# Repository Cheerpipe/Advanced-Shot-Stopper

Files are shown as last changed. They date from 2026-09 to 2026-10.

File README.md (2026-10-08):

<p align="center">
  Open Brew by Weight
</p>

# Open Brew by Weight

Open Brew by Weight adds brew-by-weight to an espresso machine: a Bluetooth
scale measures the drink, and an ESP32-S3 controller requests a stop near your
recipe's target weight. You keep using the machine's physical brew switch.

This repository provides firmware and hardware guidance for a DIY installation.
It is a work in progress, not a ready-to-install or certified kit. Development
started on the La Marzocco Linea Micra; other switch types have different wiring
and stop behavior.

> Before installation, read [Hardware](docs/HARDWARE.md) and complete the
> applicable [bench checks](docs/MANUAL_TEST_PLAN.md). The relay must remain open
> on startup, reset, power loss, and safety failure. Machine-specific wiring
> instructions are incomplete. See the [Disclaimer](#disclaimer).

## Start here

| I want to… | Read |
| --- | --- |
| Check whether my equipment fits | [Requirements](#requirements) and [machine types](#machine-types) |
| Prepare hardware and firmware | [Hardware](docs/HARDWARE.md) → [Build and USB installation](docs/BUILD.md) |
| Choose a controller and machine build | [Hardware and machine build profiles](docs/BUILD_PROFILES.md) |
| Connect and make the first shot | [First setup and daily use](docs/GETTING_STARTED.md) |
| Change how brewing works | [Features and settings](#main-features) |
| Integrate Open Brew by Weight with Home Assistant | [Home Assistant setup](docs/features/home-assistant.md) |
| Understand an unexpected result | [Troubleshooting](docs/FAQ.md) |
| Update or recover the controller | [OTA](docs/features/ota.md) / [Recovery](docs/EMERGENCY_RECOVERY.md) |
| Develop or contribute | [Contributing](CONTRIBUTING.md) |
| Understand the test gates | [Testing and validation](#testing-and-validation) |
| Look up a technical term | [Technical glossary](#technical-glossary) |
| Find a specific reference | [Documentation index](docs/README.md) |

## Requirements

- **Board:** the current built-in hardware profiles use an ESP32-S3 N16R8
  (16 MB flash / 8 MB PSRAM). The [development relay board](docs/HARDWARE.md#development-board)
  has a specific GPIO map; another board needs a complete reviewed profile.
- **Scale:** a supported Bluetooth model. Bookoo Themis Mini/Ultra were the
  primary development scales. Check the [model and capability table](libraries/EspressoScaleBLE/README.md#scale-compatibility);
  implemented protocols are not all equally tested.
- **Machine:** a compatible activation circuit connected only to isolated relay
  contacts, plus a physical switch input appropriate to the selected build.
- **Installation skills:** identify and verify your machine's electrical
  connections, build the firmware, and test the installation on a bench.

A [printable enclosure](docs/HARDWARE.md#3d-printable-enclosure) is included in
standard and thicker versions. PETG is recommended for the thick pair in
warmer installations.
Classic ESP32, boards without PSRAM, and Timemore scales are outside the current
support scope.

## How it works

The controller reads your brew switch separately from the machine's activation
circuit. It can therefore interpret your gesture and stop brewing according to
the scale, recipe guards, or time limits.

On paddle machines, the relay remains closed while brewing and opens to stop.
On momentary machines, it copies button presses and sends a pulse to request a
stop. **Opening that relay alone does not necessarily stop a momentary machine.**
See the distinctions below before choosing a build.

## Machine types

Prefer a named [hardware and machine build profile](docs/BUILD_PROFILES.md).
The selected machine profile resolves the corresponding compile-time type; it
is not a Web UI setting.

| Build | Value | How the controller knows the group is running |
| --- | ---: | --- |
| [Paddle / latch](docs/settings/paddle.md) | 0, default | Follows the maintained brew contact. Developed first for the Linea Micra. |
| [Momentary](docs/settings/momentary.md) | 1 | Infers flow from scale readings. Without confirmed flow, an automatic stop pulse may not be sent. |
| [Momentary + reed](docs/settings/momentary.md) | 2 | Uses an additional reed/hall input to observe the machine state. Preferred for momentary installations. |

Support for a switch model is not certification of a particular espresso
machine. The firmware's 60 s relay limit and the ability to stop water flow
are different on momentary machines; read the [stop limitations](docs/settings/momentary.md#stopping-and-time-limits).

This illustration shows the paddle-connector routing used during Micra
development. It is not a wiring schematic or pinout; verify the actual machine
circuit and follow the [hardware safety guidance](docs/HARDWARE.md) before installation.

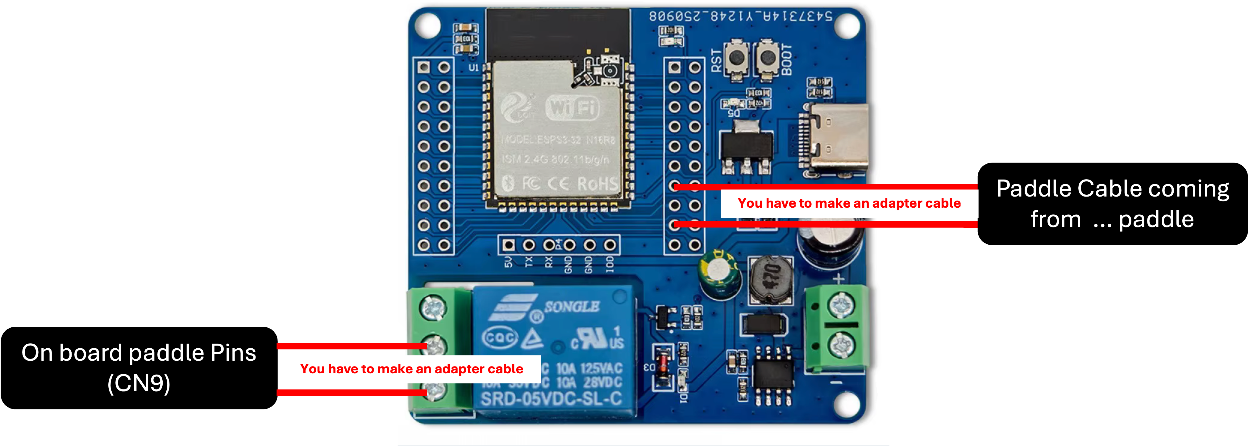
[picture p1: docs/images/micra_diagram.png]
Micra paddle connector and adapter-cable routing on the relay board


## Main features

| Need | Feature |
| --- | --- |
| Stop near a recipe weight | [Brew by weight](docs/features/brew-by-weight.md), with learned drip compensation |
| Use different recipes | [Presets](docs/features/presets.md), including factory Single and Double |
| Integrate with a Linea Micra | [La Marzocco Cloud](docs/settings/linea-micra.md) reads and sets preset brew-boiler temperatures and recognizes when the paddle is waking the machine instead of starting a brew |
| Place the cup after starting | [Tare and retare](docs/features/tare-retare.md) |
| Handle cup removal or bumps | [Cup protection](docs/features/cup-protection.md) |
| Handle unexpectedly fast or slow shots | [Fast](docs/features/fast-extraction-guard.md) and [Slow](docs/features/slow-extraction-guard.md) guards |
| Limit a shot after scale loss | [A→M time guard](docs/features/auto-to-manual.md) |
| Rinse with a switch gesture | [Quick rinse](docs/settings/quick-rinse.md), with a machine-profile default |
| Hear local feedback | [Alerts](docs/alerts.md), subject to scale/buzzer capabilities |
| Review results | [Shot history and statistics](docs/features/shot-history.md) |
| Integrate with Home Assistant | [Home Assistant](docs/features/home-assistant.md) |
| Update safely over Wi-Fi | [Dual-slot OTA](docs/features/ota.md), with automatic rollback |
| Send events to another local receiver | [Local HTTP webhooks](docs/features/webhooks.md) |

## Main settings

Recipe settings live in **Settings → Brew**. Machine and scale settings are
shared across recipes. [Presets](docs/features/presets.md) explains what is saved
and what a Home Quick Settings change affects.

The [documentation index](docs/README.md#settings) links each settings group.
Defaults are starting points; Fast and Slow guards can intentionally finish
above or below the target weight.

### Brew by weight: offset and learning factor

**Linear regression + offset correction** (`legacy` in API/CSV) applies the
full final-weight error to its learned stop offset. **Linear prediction +
adaptive EWMA** applies a fraction, α, of that error. Both stop toward
`target − learned offset`; **Baseline offset (g)** is the saved reset value
for either method, not an additional compensation.

For an eligible EWMA shot, `next offset = clamp(offset + α × (final − target), 0, 5)`.
For example, with target 36 g, final weight 36.20 g and offset 1.50 g:

| Current α | Next offset |
| --- | --- |
| 0.10 | 1.52 g |
| 0.30 | 1.56 g |
| 0.60 | 1.62 g |

A larger α responds faster to changes but also follows individual-shot noise
more strongly. A smaller α smooths that noise but adapts more slowly. An
underweight result reduces the offset so the next cutoff occurs later.
α learns between shots; it does not filter live scale readings or guarantee
better accuracy on a particular machine.

**Baseline learning factor (α)** is saved per preset, from 0.01 to 1.00 in
steps of 0.01, initially 0.30. Saving either base preserves current learning.
**Reset learned stop offset to baseline** resets only the selected offset;
EWMA keeps its current α. **Reset EWMA learning** restores both saved bases,
marks α initial and clears its evidence. Automatic learning may subsequently
choose 0.10, 0.30, 0.50 or 1.00; a custom α remains active until a candidate
earns a switch. See [BBW learning](docs/features/brew-by-weight.md#cutoff-behavior-and-learning)
for eligibility, comparison windows and persistence.

## First connection

After installation and bench verification, follow
[First setup and daily use](docs/GETTING_STARTED.md). It covers connecting to the
controller's access point, opening the Web UI, joining home Wi-Fi, selecting a
scale, and making the first shot. Once the controller has joined your home
Wi-Fi, reach the Web UI at `open-brew-by-weight.local`. Factory network details
are in [AP → First connection](docs/settings/ap.md#first-connection).

## Admin

Home and Settings use a browser claim; privileged actions also require Admin
unlock with the device password. These are separate controls:
[Web access](docs/GETTING_STARTED.md#web-access) explains both.

## Technical features

- [OTA updates](docs/features/ota.md) use an inactive firmware slot and boot
  verification. A bootable previous image is required for rollback.
- [Emergency recovery](docs/EMERGENCY_RECOVERY.md) restores access or resets
  settings using the physical switch.
- [Build and script reference](docs/SCRIPTS.md) covers supported ESP-IDF tooling.
- [Hardware and machine build profiles](docs/BUILD_PROFILES.md) defines the
  complete JSON profile, compatibility, override, and artifact contracts.

Remote start and rinse are **disabled by default**. A deliberate development
build can enable them; they are not part of the default operating workflow.
Remote Stop still requires Admin unlock. MQTT and persistent remote-control
integrations are outside the project goals. The Web UI provides status and
shot summaries, not a guaranteed real-time telemetry stream.

## Documentation

Use the [complete index](docs/README.md) for user guides, settings, architecture,
validation, and library integration. Read only the page needed for your task;
parameter tables and protocol contracts have one canonical home.

### Testing and validation

A **gate** is the set of checks that a change must pass before it can be accepted.
The project first classifies the changed files by risk, then runs the matching
gate. Higher levels include the lower-level checks, so a safety-critical change
receives much more scrutiny than a wording correction. The authoritative rules
and exact commands are in [Validation gates](VALIDATION.md).

| Level | What it is for | What it checks | When it runs |
| --- | --- | --- | --- |
| R0 | Non-critical documentation and repository metadata | Documentation contracts, local links, headings, images, and known paths | For documentation-only changes and as the base of every higher gate |
| R1 | Web UI, tests, developer tooling, and isolated logic | R0 plus the normal host tests and any focused checks or generated assets relevant to the change | While developing these areas and before submitting the finished change |
| R2 | BLE, networking, saved data, OTA, and build changes | Full host coverage, ASan/UBSan, TSAN, architecture rules, Web contracts, and every built-in compatible profile pair | When a change can affect integration, concurrency, memory safety, or a firmware image |
| R3 | Relay and machine control, ISR, watchdog, boot, GPIO, partitions, remote control, or an unknown path | R2 plus stricter compiler warnings, cppcheck, build variants, and the applicable HIL/manual evidence | Before accepting any safety-critical or not-yet-classified change |
| Release | A firmware image intended for distribution or installation | The complete automated analysis plus resource budgets, applicable soak tests, HIL, and the manual test plan | For a release candidate; a passing automated R3 run alone is not release approval |

**Host tests** run on the developer computer, without an ESP32 or
espresso machine. They are quick feedback for software behavior, but cannot prove
that real wiring, timing, radio conditions, or machine stopping are safe. The
focused profiles are:

| Profile | Purpose | When to use it |
| --- | --- | --- |
| `normal` | Runs the broad functional host suite without a sanitizer | During ordinary development and in every R1-or-higher gate |
| `asan` | Runs the host suite with ASan and UBSan to expose memory errors and undefined operations | For R2/R3 changes and when investigating crashes or suspicious memory behavior |
| `tsan` | Runs concurrent host scenarios with TSAN to find unsafe access to shared data | For R2/R3 changes and whenever task or thread ownership changes |
| `web` | Verifies generated Web UI assets and browser-facing contracts | After changing the Web UI, its source assets, or asset generation |
| `ble` | Focuses the normal host suite on scale protocols and BLE radio behavior | After changing scale communication or BLE protocols |
| `ota` | Exercises OTA host logic plus command-line and Web resilience cases | After changing firmware-update behavior or its interfaces |
| `tooling` | Checks the developer command facade, risk classification, and validation contracts | After changing scripts or repository workflow rules |

Run these profiles locally with `./scripts/dev test <profile>` and the risk
gates with `./scripts/dev validate --risk R0..R3`; `./scripts/dev classify`
determines the gate required for the changed paths. These commands do not
flash a board, operate the relay, or replace required HIL and manual evidence.

### Technical glossary

| Term | Meaning in this project |
| --- | --- |
| α (alpha) | The learning factor used by adaptive EWMA. It controls how much the latest eligible shot changes the learned stop offset. |
| A→M | **Automatic-to-manual** transition: brew-by-weight can no longer rely on the scale, so a time guard limits the remaining shot. |
| Admin unlock | A password-protected authorization required for privileged Web UI actions; it is separate from claiming the browser session. |
| AGPL-3.0 | GNU Affero General Public License version 3, the repository's current copyleft license. Network use of a modified version can require offering its corresponding source code. |
| AI | Artificial intelligence. The README notes its use during project development. |
| API | Application Programming Interface: a defined way for software components or external integrations to exchange commands and data. |
| ASan | **AddressSanitizer**, a host-test instrument that detects invalid memory access, such as reading past a buffer or using freed memory. |
| BLE | Bluetooth Low Energy, the wireless link used to communicate with supported scales. |
| BBW | **Brew by weight**, the feature that uses live scale measurements to request a stop near the recipe target. |
| Baseline | A saved starting value to which learned settings can be reset. It is not an extra correction added to the current value. |
| Boot / boot verification | Boot is the controller's startup process. After OTA, verification confirms that the new image started safely before it is kept. |
| Browser claim | The controller's way of assigning ordinary Home and Settings access to a browser session; it does not grant Admin privileges. |
| CI | Continuous Integration, the practice of running automated checks on every change. This repository runs its checks locally through `./scripts/dev` instead of a hosted pipeline. |
| Clamp | To restrict a calculated value to a minimum and maximum; the README's formula keeps the learned offset between 0 g and 5 g. |
| Compile-time setting | A choice fixed while firmware is built. Changing it requires a new build; it cannot be changed later in the Web UI. |
| CSV | Comma-Separated Values, a plain-text tabular format used when exporting or exchanging shot data. |
| Cutoff / stop offset | The point at which the controller requests a stop before the target weight, allowing for coffee that continues to drip. The learned offset is adjusted from previous eligible shots. |
| DIY | Do it yourself: the user assembles, installs, and validates the hardware rather than receiving a certified finished product. |
| Drip compensation | Stopping early enough to account for liquid that continues reaching the cup after the machine receives the stop request. |
| ESP32-S3 | The Espressif microcontroller family on which the controller firmware runs. |
| ESP-IDF | Espressif IoT Development Framework, the supported toolchain and software framework used to build the firmware. |
| EWMA | Exponentially Weighted Moving Average, the adaptive learning method that applies a chosen fraction of the latest final-weight error instead of the entire error. |
| Firmware | Software built to run on the ESP32-S3 controller rather than on the user's computer or browser. |
| Firmware slot | One of the flash-memory regions that can hold a bootable firmware image. OTA writes the inactive slot so the previous image remains available for rollback. |
| Flash memory | Non-volatile storage that keeps firmware when power is removed; it is distinct from working memory such as PSRAM. |
| Gate | The complete set of automated checks and, where required, physical evidence demanded for a change's risk level. |
| GPIO | General-Purpose Input/Output, a configurable electrical pin used to sense a switch or control a signal. Its assignment and polarity are safety-critical here. |
| Guard | A protective rule that stops or limits a shot when measured behavior is outside the recipe's expected conditions. |
| HIL | Hardware in the loop: testing with the real controller or representative electrical hardware so physical timing and I/O behavior can be observed. |
| Host test | A test compiled and run on a computer, without operating the ESP32, relay, or espresso machine. |
| HTTP | Hypertext Transfer Protocol, used by the local Web UI, webhooks, and update-related interfaces. |
| ISR | Interrupt Service Routine, code that responds immediately to a hardware event and must obey stricter timing and concurrency rules. |
| K2 | The README's example name for an optional external safety relay or barrier; its actual design depends on the machine and jurisdiction. |
| MB | Megabyte, used here to describe flash and PSRAM capacity. |
| MIT License | The permissive license that applies to identified upstream portions and historical snapshots, not to the repository's current work as a whole. |
| Momentary machine / pulse | A momentary machine changes state after a brief button-like electrical signal, called a pulse, rather than following a maintained switch position. |
| MQTT | Message Queuing Telemetry Transport, a publish/subscribe messaging protocol; persistent MQTT remote control is outside this project's goals. |
| n8r4 / n16r8 | Supported memory variants: the number after `n` is flash capacity in MB and the number after `r` is PSRAM capacity in MB. |
| OTA | Over-the-air update: installing firmware over Wi-Fi into an inactive firmware slot, followed by boot verification and possible rollback. |
| Paddle / latch | A maintained physical switch: its state directly represents the requested brew state. |
| PETG | Polyethylene terephthalate glycol, a 3D-printing material recommended for the thicker enclosure parts in warmer installations. |
| Pinout / GPIO map | The documented assignment between board pins and electrical functions. A different board requires a reviewed assignment. |
| Preset | A saved recipe and its related brew settings, such as target weight and learned values. |
| PSRAM | Pseudostatic RAM, external working memory fitted to the supported ESP32-S3 boards. |
| Reed / Hall input | A magnetic sensor input used by the preferred momentary-machine configuration to observe whether the machine is running. |
| Regression | Here, a mathematical method that estimates drip behavior from previous eligible shots to improve the stop point. |
| Relay / isolated contacts | An electrically controlled switch whose contact side is kept separate from the controller side. The project uses it to request machine activation or stopping. |
| Rollback | Returning to the previous bootable firmware image when a new OTA image fails verification. |
| Sanitizer | A test-build instrument that watches a running program for classes of bugs that ordinary functional assertions may miss. |
| Soak test | A long or repeated run used to reveal resource leaks, timing drift, or failures that short tests may not expose. |
| Static analysis / cppcheck | Inspection of source code without executing it, used to detect suspicious constructs and rule violations. `cppcheck` is one analyzer used by the R3 gate. |
| Tare / retare | Setting the scale's current load to zero; retare repeats that action when the workflow needs a new zero reference. |
| Telemetry | Status or measurement data reported while a system runs. The Web UI is not promised as a guaranteed real-time telemetry channel. |
| TSAN | **ThreadSanitizer**, a host-test instrument that detects data races: unsafely coordinated simultaneous access to shared data by multiple threads. |
| UBSan | **UndefinedBehaviorSanitizer**, a host-test instrument that detects invalid C/C++ operations whose result the language does not define. |
| USB | Universal Serial Bus, used to install firmware, monitor serial output, and issue supported maintenance commands. |
| Watchdog | A timer that detects software that has stopped making required progress and triggers a controlled recovery. |
| Web UI | The browser-based user interface served by the controller. |
| Webhook | An HTTP request sent to another local service when a configured event occurs. |
| Wi-Fi / access point (AP) | Wi-Fi is the local wireless network technology; in access-point mode the controller creates its own temporary network for first setup or recovery. |

## Disclaimer

**Use at your own risk.** Anyone who builds, installs, configures, or operates
firmware from this repository does so **under their sole responsibility**. The
authors and contributors **accept no liability** for any harm, loss, or damage
whatsoever — including but not limited to **personal injury, death, property
damage, equipment damage, business interruption, or psychological distress** —
arising from the use or misuse of this software, documentation, or any
derivative work.

You are solely responsible for:

- **Designing and building a correct, safe circuit** — suitable relay or contact,
  electrical isolation, ratings, polarity, feedback, and any external safety
  barrier (e.g. K2) appropriate for your machine and jurisdiction.
- **Installing and verifying that circuit** on your equipment, including bench
  tests and the full [manual test plan](docs/MANUAL_TEST_PLAN.md) before
  connecting to a live espresso machine.
- **Configuring the firmware correctly and safely** — including GPIO assignment,
  compile-time pin maps, polarity, machine circuit limits, and workflow parameters — so
  that paddle readback, machine control, and automatic stop behavior match your
  hardware. GPIO and other safety-critical pin assignments are **not**
  configurable from the Web UI; they must be set in source and verified at
  build time (see [Hardware](docs/HARDWARE.md) and the [FAQ](docs/FAQ.md)).

**Espresso machines are inherently hazardous.** A machine such as the La
Marzocco Linea Micra contains **pressurized boilers, hot water, and steam at high
temperature**. Adding automatic or remote control — including brew-by-weight
stop, relay actuation, Wi-Fi commands, and timer-based limits — can increase
risk if wiring, isolation, configuration, or software behavior is wrong.
Malfunction or misconfiguration could leave the brew circuit energized too long,
defeat intended safety interlocks, or cause scalding, flooding, electrical
hazard, or fire. **Do not connect this firmware to mains-powered espresso
equipment unless you understand these risks and have validated your entire
system on the bench first.**

This project provides software and documentation only. It **does not**
certify, warrant, or guarantee safe operation on any machine. No statement in
this repository should be interpreted as professional electrical, plumbing, or
machinery safety advice.

This project was developed with substantial assistance from artificial
intelligence tools. AI helped with design, implementation, documentation, and
testing workflows; human review, hardware validation, and safety judgment remain
the author’s responsibility. Use on real espresso equipment only after you have
verified wiring, isolation, and behavior on your own setup.

## License

Open Brew by Weight is licensed under the
[GNU Affero General Public License v3.0](LICENSE) (AGPL-3.0).

You may use, modify, and distribute it freely, including for commercial
purposes. If you distribute a modified version, or offer one to users over a
network, you must provide the complete corresponding source code under the
AGPL. Closed proprietary forks are not allowed.

Earlier snapshots of this repository were published under the MIT License.
Those historical releases remain available to their recipients under MIT.
Portions derive from [tatemazer/AcaiaArduinoBLE](https://github.com/tatemazer/AcaiaArduinoBLE)
(MIT); see [LICENSE](LICENSE) for the full terms and upstream notice.

## Credits

Open Brew by Weight is maintained by **Felipe Urzúa**
(`cheerpipe@gmail.com`) —
[Cheerpipe/AcaiaArduinoBLE](https://github.com/Cheerpipe/AcaiaArduinoBLE).

It would not exist without
**[tatemazer](https://github.com/tatemazer)** and
[tatemazer/AcaiaArduinoBLE](https://github.com/tatemazer/AcaiaArduinoBLE).
That project proved BLE brew-by-weight stop, shared the core scale protocol
work, and shipped the original Shot Stopper as a plug-and-play kit. This
application firmware, Web UI, paddle and momentary machine models, and safety
workflow are new work on top of that foundation.

Thanks to **[AtomHeart-Lang](https://github.com/AtomHeart-Lang)** for AtomHeart
Eclair scale support, contributed upstream in
[tatemazer/AcaiaArduinoBLE#41](https://github.com/tatemazer/AcaiaArduinoBLE/pull/41).
That work is vendored here and keeps Eclair in the supported scale set.

The vendored library also credits:

- [LunarGateway](https://github.com/frowin/LunarGateway/) (frowin)
- [pyacaia](https://github.com/lucapinello/pyacaia) (lucapinello)
- Felicita Arc: baettigp, A-TWJ
- Bookoo: philgood, same31
- AtomHeart Eclair: [AtomHeart-Lang](https://github.com/AtomHeart-Lang)
- Decent, DiFluid, MyScale, Varia, Eureka, WeighMyBru: protocol knowledge from
  [gaggimate/esp-arduino-ble-scales](https://github.com/gaggimate/esp-arduino-ble-scales)
  ([jniebuhr](https://github.com/jniebuhr) et al.), reimplemented here without
  copying source
- Lunar 2019: jniebuhr

See the [library acknowledgement](libraries/EspressoScaleBLE/README.md#acknowledgement).

Runtime and tooling:

- [Espressif ESP-IDF](https://github.com/espressif/esp-idf)
- [Arduino-ESP32](https://github.com/espressif/arduino-esp32)

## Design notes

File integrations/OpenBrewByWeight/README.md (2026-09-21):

# Open Brew by Weight for Home Assistant

This HACS custom integration connects Home Assistant 2026.9 or newer to one
Open Brew by Weight controller over the local network. It provides live shot
state, controller-restored shot measurements, durable preset selection, seven
Home Quick Settings switches, and a safe restart button. It never starts or
stops the espresso machine.

## Install

After the dedicated integration repository publishes a release, add that
repository to HACS as an **Integration**, install **Open Brew by Weight**, and
restart Home Assistant. During development, copy
`custom_components/open_brew_by_weight` into Home Assistant's
`custom_components` directory.

The controller must run firmware with integration API version 1. Set Home
Assistant's Internal URL to a LAN-reachable `http://` address. Both devices must
be on the same trusted network.

## Configure

If the controller is on a network that passes multicast, it appears
automatically under **Discovered** in **Settings → Devices & services**;
confirming it is the only step needed. Otherwise add **Open Brew by Weight**
manually and enter the controller IP address or local host name. Confirm
webhook takeover only if Home Assistant should replace the existing receiver.

Setup registers and tests the local callback before entities appear. The
controller API is intentionally open on the trusted LAN, like its Web UI. The
webhook ID is not included in entities or diagnostics.

## What it provides

- One controller device and 17 translated sensors.
- Last completed and last qualifying-good shot values: duration, final and
  target weight, average flow, first drop, type, stop detail, and preset name.
- A non-optimistic **Active preset** select backed by stable preset IDs.
- Seven non-optimistic Quick Settings switches and a shot-safe **Restart Open
  Brew by Weight** button.
- Immediate webhook updates with bounded reconciliation after commands,
  revision gaps, controller startup, or runtime failure; no periodic polling.
- Transactional address/webhook reconfiguration, redacted diagnostics, clean
  unload, and conditional removal cleanup.

A “good” shot retains the former YAML example's continuity rule: over 12
seconds and over 2 grams. It is not a quality rating.

## Limitations and common errors

- The controller supports one HTTP callback and no HTTPS callback.
- The controller API has no authentication and relies on the trusted LAN.
- Webhook delivery is best effort; a missed final event may remain stale until
  the next command, revision gap, controller-start hint, or reload.
- Preset and Quick Settings changes are rejected while the controller's
  existing safe-state gate is closed. Restart may be requested during a shot
  but waits until the controller is idle.
- A silent power loss cannot be detected before a REST operation fails because
  the integration deliberately has no polling heartbeat.
- Automatic discovery needs multicast on the network; guest and hotel Wi-Fi
  that blocks it falls back to manual IP/host setup.

Use **Reconfigure** to view or rotate the administrator-only webhook ID, change
the address, or resend/test the current callback. Deleting the entry clears
only a callback it still owns.

Full setup, migration, entity, update, and troubleshooting details are in the
[Home Assistant guide](../../docs/features/home-assistant.md). The wire contract
is in the [Integration API](../../docs/INTEGRATION_API.md).

## License

Copyright 2024–2026 Felipe Urzúa and contributors. This integration is licensed
under AGPL-3.0-or-later with the rest of Open Brew by Weight.

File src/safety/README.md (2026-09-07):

# Safety service boundary

Safety remains behind the stable root headers while R3 extractions require HIL.
Do not move relay, timer, watchdog, boot, or GPIO behavior together with a
functional change. The root `AGENTS.md` invariants and `VALIDATION.md` R3 gate
apply to every file in this directory.

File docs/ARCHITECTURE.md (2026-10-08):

# Firmware architecture and ownership

Use this reference when changing module boundaries. For the runtime sequence,
read [State machines](STATE_MACHINES.md); for a first code change, start with
[Contributing](../CONTRIBUTING.md).

The integration roots `src/openBrewByWeight.cpp` and `src/OpenBrewByWeightNetwork.cpp`
assemble implementation fragments in `src/control/`, `scale/`, `network/`,
`persistence/`, `diagnostics/`, and `platform/`. Fragments compile in their
owning translation unit. Shared headers carry fixed-size values, pure policy,
or explicit callback tables; each service owns its mutable state.

| Service | Owns mutable state | Accepts | Publishes |
|---|---|---|---|
| SafetyKernel | relay, safety timers, watchdog and reset history | bounded control intention | `RelaySafetySnapshot`, safety events |
| ControlOrchestrator | active session, cup/recipe policy and command arbitration | scale/machine/network messages | fixed-size control snapshots and commands |
| ScaleService | BLE central link, scale queues and radio policy | `ScaleCommand`, immutable worker policy | `ScaleEvent`, `ScaleLinkSnapshot`, RF state callback |
| SelectedMachineIntegration | concrete machine integration state; absent integrations use a no-op adapter | common lifecycle/config, physical-start disposition and optional backflush contract | normalized bounded backflush observations plus private feature status; no universal feature model |
| NetworkService | Wi-Fi/httpd/mDNS, request parsing and webhook transport | `NetworkBridgeCallbacks`, control snapshots | `WebCommand`, transport diagnostics |
| PersistenceService | NVS/EEPROM/partition serialization and write schedule | fixed-size records | success/failure result messages |
| DiagnosticsService | logs, counters, task/heap snapshots and exports | observational snapshots | JSON/serial evidence only |

## Dependency rules

1. SafetyKernel never includes or calls Wi-Fi, HTTP, JSON, webhook or network
   code. Its ISR path remains fixed-size, internal-memory-only and nonblocking.
2. ScaleService never references the `networkManager` singleton. Radio state
   crosses `ScaleWorkerBridgeCallbacks`, configured once before its task starts.
3. NetworkService requests control effects only through
   `NetworkBridgeCallbacks`; it cannot call machine/relay implementation APIs.
4. Persistence owns durable writes. Other services publish fixed-size requests
   and do not hold task/spin locks across flash I/O.
5. Diagnostics are observational. No diagnostic result authorizes the relay or
   mutates session state.
6. C task handles are borrowed lifecycle tokens: their owner must execute
   stop/ack/join. Other ESP/FreeRTOS handles use a unique non-allocating owner
   or an explicitly documented static lifetime.
7. Common machine-integration code exposes lifecycle hooks, physical-start
   disposition and an optional normalized backflush observation contract.
   Native protocol, authentication and provider policy remain in the selected
   module. Unsupported integrations return no permission. CMake compiles exactly
   one concrete adapter and only its private component dependencies.

`scripts/check_architecture.py` gates these rules and caps growth of the three
legacy concentration points. The caps are not quality targets: when a feature
would exceed one, extract it into its owning service rather than raising the
limit. Current independent host harnesses exercise SafetyKernel, OTA,
persistence, webhook policy, BLE protocol/runtime and shared resource owners
without including either monolithic integration root.

## Machine integration modules

The machine profile declares an allow-listed `integration` value explicitly;
brand, model, ID and display text never select executable code. Profiles with
`integration: none` compile the no-op adapter and do not link a concrete machine
protocol component. Linea Micra builds compile its adapter, service, bounded
feature types, HTTPS cloud client and the pinned WSS/STOMP observer. Future machines may expose entirely
different feature APIs while retaining only the small lifecycle boundary needed
by boot, network-state publication, and generic physical-start disposition.

The Micra adapter owns a dedicated low-priority worker, bounded PSRAM response
workspace, and a PSRAM-only mbedTLS allocation profile so transient handshakes
do not fragment internal DRAM. It registers an installation key, signs La
Marzocco cloud requests, keeps short-lived access and refresh tokens in RAM,
lists account machines, and reads only the selected serial's dashboard. The
network service publishes STA, AP, and shot state through the common lifecycle
boundary. The worker never starts cloud work without STA, cancels it when AP
starts or STA is lost, and pauses state observations during shots. It has no
NimBLE dependency and cannot delay scale discovery, scale commands, or weight
delivery.

The Micra service also owns power-state freshness and the optimistic ON/OFF
overlay lifetime.
Its adapter returns normal, wake, backflush-candidate or cleaning-blocked
physical-start dispositions. Control consumes them before brew, rinse, guards
and scale effects; those subsystems never depend on Micra types.

Backflush uses an optional common bounded handoff of eight ordered transitions,
copied under the integration mutex and drained only by control. Opaque
continuity, episode and first-ingress attempt tokens fence discontinuities and
pre-edge frames. Micra owns native state, transport liveness and qualification;
control owns candidate/running activity without a brew session. The existing
relay driver alone promotes a live 60-second candidate to the original close
time plus 180 seconds, transactionally replacing its independent and task
deadlines. Every non-active state after confirmation, observation loss, physical
release or safety failure opens the relay. The end path appends one electrical
duration record without scale commands, shot statistics or brew events.

The schema-3 settings blob retains the 312-byte
`LineaMicraPersistedSettings` record in every profile. The connection byte at
record offset 311 occupies prior enclosing-blob padding: Micra offset 2991,
checksum offset 3304 and total size 3312 remain unchanged. Values are explicitly
WebSocket=0 and API=1. Schema 1/2 blobs are authenticated against their original
CRC before an in-memory migration defaults the new byte; v1 also enables the
existing touch-stop fallback. Load never writes back. Settings saves and resets
wait for successful OTA trial confirmation, preserving the old durable records
for rollback. This admission does not gate boot readiness or other stores.

One facade reduces HTTP and WebSocket field updates. Each admitted subscription
queues one initial dashboard cycle in the existing HTTP worker, concurrent with
push reception. Its identity, epoch, connection revision and independent field
revisions are captured at subscription; ordinary reads capture them at request
start. Both capture intent at request start; callbacks capture intent when a
fragmented message starts. Old results cannot overwrite newer push evidence or
offline/reconnect transitions. Compatible queued reads coalesce; post-command
reconciliation retains its request-time field baseline. Accepted power alone
changes its source (`api_initial`, `api`, `websocket`) and synchronization.
WebSocket power stays current during healthy silence; API mode retains its
30-second age limit. Accepted commands do not fabricate power/temperature samples.
A 60-second optimistic overlay and a separate stale suspension hold preserve
the effective power without changing the last cloud evidence timestamp.
The SDK callback publishes decoded updates under the facade mutex, independently
of the HTTP worker. Only the worker stops/destroys the WebSocket.
Observation pauses require both an admitted shot and a currently connected
scale. Scale loss or rinse classification releases the pause. Unscaled shots,
wake, backflush and rejected starts keep observation available. Actual-shot
command safety and relay-critical webhook/NTP admission remain independent
of the scale-qualified transport pause.

Scale discovery publishes a generic atomic inhibit before exposing an eligible
Candidate mailbox. Micra HTTP, webhooks and NTP consume it, regardless of
machine profile. Discovery releases acquisition at Ready, or after five seconds
of actual scan opportunity without a candidate. Setup, shot and the library's
three-second quiet interval remain separate gates. Local access remains active;
this is transport quiescence, not a physical RF-silence guarantee. Micra WSS is
excluded from the scale inhibit so backflush supervision survives BLE acquisition.

## BBW policy and storage

Brew-by-weight uses a single cutoff policy: linear prediction with adaptive
EWMA learning (the regression mode was removed; persisted `algorithm=0`
blobs are aliased to EWMA at settings load). Shared scale qualification,
direct confirmation, guards, control arbitration and machine/safety authority
remain outside the policy. The original trend fit remains shared with accidental
touch sensing; only EWMA cutoff uses centered OLS. Strategies neither actuate
hardware nor write flash.

Control owns `BbwLearningBank`: up to eight identity-keyed states, under 3,000
bytes total, with 20 observations and five trajectory anchors per preset.
Four fixed gains compete against the current gain, including a custom incumbent.
Scoring replays the retained window from its anchors and is bounded
post-finalization work, with no allocation or per-sample persistence. The cycle
and pending finalizer capture preset, algorithm/profile, full-precision offset,
actual alpha and a per-learner generation. Learning checks the originating state;
reset/delete/recreation or a conflicting update invalidates it. Recipe changes
clear evidence; algorithm-only selection freezes/resumes retained EWMA state.
Editing reset bases alone preserves current learning and evidence.
Settings status publishes active-preset identity, both offsets, alpha baseline, gain/provenance
and evidence count together in the existing coherent control snapshot.

Settings schema 3 uses the current 344-byte `RuntimeConfig`, 104-byte
`ShotPreset`, and 3,312-byte settings blob. Candidate
anchors/observations/generations are RAM only; deferred persistence retains
offsets, gain/provenance, and profile through the existing dual-slot owner.
`powerManagementEnabled`, webhook preset delivery, and Allow rinse while Armed
are current explicit fields. Presets never copy the global power setting.
The schema-1 upgrade names former padding at runtime byte 17 and preset byte 46
for `touchStopFallbackEnabled`; it initializes both to true before semantic
validation. Schema-2/3 records preserve explicit false. Blob sizes, revisions and
dual-slot ownership remain unchanged. Other lengths and schemas are rejected.
The shot log is the authority for a completed shot: confirmed, non-rinse,
strictly more than 12,000 ms of brewing and a finite settled yield strictly
above 2 g. The fixed recording threshold does not alter the configurable BBW
protection window or actuation. Home and the integration snapshot resolve the
newest eligible log record by ID under `shotStoreMutex`; the curve sidecar and
rating use that same ID. Deleting the newest record advances Home to the next
eligible row, and clearing the log empties the idle card. The in-progress card
continues to use the live control snapshot. The legacy `LastShotStore` blob
remains in the binary layout for internal completed-cycle diagnostics, but its
separate good-shot field is not a public shot authority. An erase-all install
starts both histories empty; no upgrade migration is required.

History schema 1 keeps the current fixed records and entries. Guard byte bits 5–7 encode
profile (0 unknown, 1 pre-selector regression with unknown version, 2 regression v1,
3 adaptive EWMA v1, 4 EWMA v2). Alpha is 0 unknown or 1–100 hundredths;
extension bits 2–4 hold its low three bits, cut-type bits 4–7 its high four.
Extension bits 5–6 encode learning application (0 unknown,
1 skipped, 2 applied). Guard, rating, extension and weight-source meanings are
preserved in the current layout. Shot-type bits 2–7 and cut-type
bits 2–3 hold the captured preset ID (low six/high two bits); type/cut readers
mask the low two bits. Preset/BBW writers preserve each other's bit fields.
Any non-v1 history store is discarded instead of decoded. The ID follows
existing preset allocation, while the stored name is historical data rather
than a lookup through the current preset bank.
Stats values are derived under the store mutex from shot records in RAM;
no aggregate is persisted. The read visits at most 100 ring entries and copies
at most ten records for general metrics. BBW error has its own ten-cut window
across the same ring, counting normal target or legacy prediction cuts only.
Available flow is counted separately within the general window.

The stats shot log, its curve sidecar, and the independent activation history
are owned by one RAM data layer (`ActivationStores`) whose every access runs
under the single `shotStoreMutex`. Control and HTTP mutate only RAM and advance
a generation. Control housekeeping captures an immutable image under that
mutex: clean shot/activation stores skip their record payloads, and the curve
image carries only the uncommitted suffix plus block, deletion and epoch metadata.
Oldest-first curve commits preserve this suffix across retries and ring eviction.
The image is dispatched to the core-0 persistence worker. The worker performs
flash I/O without the store mutex. Control acknowledges completion and clears
live dirtiness only when the completion generation still matches.
Acknowledgement carries the image's
flash progress back to each live store even when newer RAM edits remain dirty,
so the next snapshot advances from the committed physical state. ShotLog and
History keep their two-slot generations; curves use block sequences, retention
floors and clear epochs. The manual scale
profiler follows the same deferred pattern: the health worker owns one
bounded PSRAM capture of raw decoded weights plus correlated firmware
decisions, and the persistence worker commits the completed trace to a
dedicated flash partition with the validity-bearing header written last.
Capture ends at record capacity or on request, with a reserved terminal slot;
there is no elapsed-time cutoff. Its 256 KiB PSRAM payload and 256 KiB flash
payload hold the same trace, so they are not additive capacity. The health
worker maintains a constant-memory, time-based EWMA of record growth for the
advisory remaining-time estimate. Persistence state remains separate from
capture occupancy. Existing record/header fields extend timestamps without
changing the 32-byte record size or partition layout; see the
[diagnostic API](INTEGRATION_API.md#post-apiv1diagnosticscale-profile).
Each inactive slot or used curve sector is
erased one 4 KiB sector at a time, programmed one 1 KiB staged chunk at a time,
and receives its validity-bearing header last; the worker rechecks the current
machine and scale gates between steps. The shot log's whole 10,828-byte store and the
16,024-byte activation-history store live in PSRAM and move to and from their
slots in 1 KiB chunks staged through the small internal flash-I/O scratch only
while that owner holds the flash lock. Each keeps two slots in its own data
partition — 2×12 KiB for `shotlog`, 2×16 KiB for `history` — with generation
and checksum selection preserving the atomic whole-store update; a failed
write never erases the last-good slot. Writes remain deferred until the shot
has ended. The shot log uses schema 2 in its dedicated partition; any other
schema is discarded and the shot history starts empty.

On n16r8, ESP-IDF writes one ELF core dump to a 640 KiB capture partition
after a panic. Once the relay is open and the durable boot ID has been saved,
boot code validates that image and promotes it into one of two 704 KiB slots
in the crash-history partition. Each slot commits a checksum-protected metadata
sector last, after the dump copy and SHA-256 verification. The copy replaces
the oldest valid slot only when both slots are occupied; interruption before
commit leaves the capture available for retry. The capture's first sector is
erased only after commit, so a reboot between those operations is recognized
by the boot ID and dump digest. HTTP download reads bounded chunks under the
shared flash lock and releases the lock before sending each chunk. The raw
archive requires Admin unlock because task stacks may contain secrets.

The shot-curve sidecar uses schema 3. Each accepted extraction or drip weight is paired
with its relative reception time in milliseconds; repeated weights and equal
timestamps remain observations. The 1201-observation capacity covers a 60 s
shot with observations at least 50 ms apart. That spacing is a capacity
assumption, not a grid or rate limiter. Known rejected observations, reference
changes and link discontinuities mark the next accepted observation as a new
segment. Overflow preserves the prefix, marks it incomplete and leaves control
and scalar history running.

The 4984-byte RAM record and 498420-byte 100-record cache live in PSRAM.
Curve events also preserve elapsed milliseconds in 16-bit fields, with
`UINT16_MAX` reserved for unavailable values. Sidecar schema 3 distinguishes
these fields from previous decisecond events; older curve records are discarded
without changing scalar history, settings, partition addresses or OTA slots.
Curve JSON keeps the seconds-based `dropS`, `extendedS`, `atmS`, `atmClearedS`
and `endS` fields with three decimal places; scalar shot metrics retain their
existing precision and meaning.
An 816 KiB dedicated partition holds 101 reserved 8 KiB data blocks and two
4 KiB clear-epoch sectors. A maximum-size record occupies 5012 bytes. Writes
erase only its one or two used physical sectors, transfer only the used record
through the existing internal 1 KiB scratch, and commit the checksum-bearing
header last. A replacement uses the spare block, retaining the previous 100
records until commit. Startup scans only block starts, checks schema, lengths,
counts, times and checksums, and reconstructs the newest retained records.
Deletion clears a validity bit; the committed retention floor prevents old
evicted curves from returning after deletion. Alternating clear epochs prevent
curves from returning when shot IDs are reused. Immutable worker acknowledgement
carries physical progress forward while newer RAM mutations stay dirty.

Capture performs no flash I/O. After cutoff, control appends valid same-connection
drip observations to the pending curve until finalization or cup discontinuity.
The existing 1201-reading/60-second bounds include this tail; overflow retains
the captured prefix and sets `wTruncated`. Rejected readings, reference changes
and link discontinuities retain segment breaks. The cutoff event keeps its
original time; accepted post-drip yield updates its separate weight annotation.
No schema, record-size or partition change is required, and existing schema-3
records remain readable after OTA. Curve
JSON exposes aligned `wCg`/`wAtMs`, segment-start indices in
`wBreakBefore`, and `wTruncated`. Weight and flow consumers use actual
times; event annotations never become observed samples. The Web weight chart
draws post-cutoff observations dashed without fill and uses a fixed-size hollow
marker only when the complete tail's last observation matches settled yield.
Flow applies the same supported-window estimator to extraction and drip readings;
CSV includes both. Its faint, unfilled dashed continuation starts at cutoff,
with a visual-only interpolated boundary when continuous support exists.
Post-cutoff endpoint estimates with midpoints before cutoff do not alter the
earlier solid trace. Extraction Max flow excludes post-cutoff endpoints, while
the plot range includes drip rates. Scalar shot metrics,
independent Stats eligibility windows, sorting and exact-ID joins remain owned
by ShotLog. Other curve schemas start empty. OTA remains supported after the
one-time preserving USB layout transition.

Decoding checks the supplied length before reading record CRCs and copies only
that validated length; compact inputs do not require a full-store allocation.
Profile rules are immutable: changing prediction, gain candidates or eligibility
requires versioned compatibility, not relabeling historical data. Numeric and
user contracts are in [BBW](features/brew-by-weight.md#cutoff-behavior-and-learning)
and [shot history](features/shot-history.md).

## Live settings notifications

The global `timezoneId` is an IANA region/city string in the schema-3 settings
blob. Network validates it against the firmware's generated tzdata2026d
catalog; control owns the effective setting and first-auto provenance; the
existing persistence worker saves both in the same settings generation.
The `timezoneAutomatic` preference occupies former runtime padding at byte 6,
preserving the remaining layout. Saved zones and their provenance survive both
same-schema OTA updates and the supported schema-1/2 to schema-3 conversions.
Automatic time zone defaults to on for new records.
Flash persistence publishes `timezoneInitialized` only after loading a valid
saved zone or verifying a settings write containing one; factory reset clears
it. Until then, a zone-only browser initialization is permitted without Admin.
Once initialized, zone-only browser updates require saved automatic mode.
Other date/time patches, including mode changes, still require Admin. Control
rechecks the revision and automatic-update eligibility before applying commands;
the existing worker retries persistence failures without repeated UI writes.
`src/ShotStopperTimeZoneData.h` is an immutable flash table of 597 supported
IDs and 4,341 transitions, deduplicated into 67 schedules for UTC instants in
2025–2099. `scripts/generate_timezones.py` regenerates it from the pinned
upstream archive without runtime allocation or a global C library `TZ` state.
There is no mutable catalog copy or per-request allocation. On n16r8, the
existing PSRAM XIP profile places this read-only data in PSRAM at startup;
other profiles keep their configured read-only mapping. The API exposes the current
zone and the offset resolved at the current UTC instant separately. Without a
configured/resolvable zone, UTC offset zero is the explicit fallback.

The control task captures UTC and its resolved offset when a cycle ends.
Pending shot finalization keeps that pair in RAM through drip delay; the shot
and activation stores retain their existing UTC/local/offset representation
without a storage migration. NTP continues to own UTC synchronization and
does not change the monotonic control timers. The Web preview resolves a draft
zone without saving it; a browser UTC estimate is used only for preview when
the controller clock is unavailable.

First-auto provenance reads UTC once under the wall-clock owner's lock so
its timestamp and quality cannot disagree during an NTP state transition.
Configuration and preset saves are acknowledged by their request ID and
result, together with the resulting revision; unrelated revision changes do
not acknowledge a pending command. Applied settings may still await the
existing asynchronous persistence worker.

Live settings commit publishes the new runtime snapshot, then dispatches a
fixed, allocation-free table of subscriptions on the control task. Each owner
provides its own old/new value predicate and callback; the settings dispatcher
knows neither the effect nor its destination. One callback runs at most once per
commit even when several of its input fields change. The NTP subscription
publishes the new network snapshot and its change generation under the same
data lock; the network task performs the rearm. Other settings commits still
publish the network snapshot without rearming NTP. Cup-placement and idle-tare
evidence likewise use separate RAM generations. Boot initialization and a
scale's initial connection retain their
own policy application paths. Persistence and status publication are independent
of these operational triggers. No callbacks run from an ISR or across a flash
write, and the OTA update path remains available. The settings layout is
schema 3, with same-layout schema-1/2 settings preserved on upgrade.

## Residual qualification

`RuntimeConfig` uses a 344-byte fixed layout inside the current schema-3
settings blob. `autoTareOutsideBrew` remains a global machine setting rather
than part of the per-shot/preset recipe snapshot. Only the explicitly supported
same-layout schema-1/2 records are converted at boot. The optional idle accessory retare uses spare bit 6 of
the already-packed `noScaleBbwMode` byte. New and factory-reset records default
on; existing saved records retain their stored bit, including OFF. The bit is
preserved when the no-scale mode changes; this bit itself does not alter the blob.

Idle tare arbitration lives in `control/OpenBrewByWeightCycleRuntime.inc`, reusing
the cup FSM's PLACED event and ScaleService's TARE_ONLY transport. Worker
request lifetime and control-owned cup provenance remain separate; see
[scale commands](STATE_MACHINES.md#scale-commands-scalecommandtype--outbound).

Source boundaries do not prove real FreeRTOS interleavings or interrupt
latency. Release evidence must still include the target trace and HIL runs in
`SCHEDULABILITY.md` and `P2_RESOURCE_BUDGETS.md`.

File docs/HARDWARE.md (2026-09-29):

# Hardware

Development board used for this firmware, default GPIO map, and wiring
warnings.

## Installation readiness

The board pin map and enclosure are documented below. Machine-specific wiring diagrams and installation photos are provided as references.

### Wiring Diagrams

- **Linea Micra**:
  Linea Micra Wiring Diagram
- **Rancilio Silvia Pro X**:
  Rancilio Silvia Pro X Wiring Diagram

### Installation Photos

**Rancilio Silvia Pro X**:
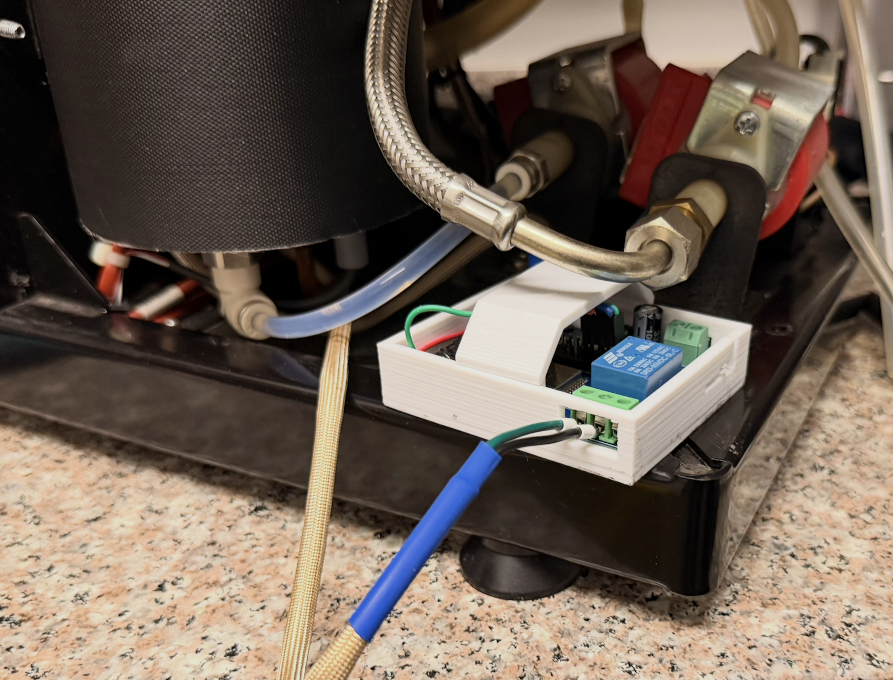
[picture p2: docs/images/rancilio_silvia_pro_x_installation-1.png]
Rancilio Silvia Pro X Installation 1

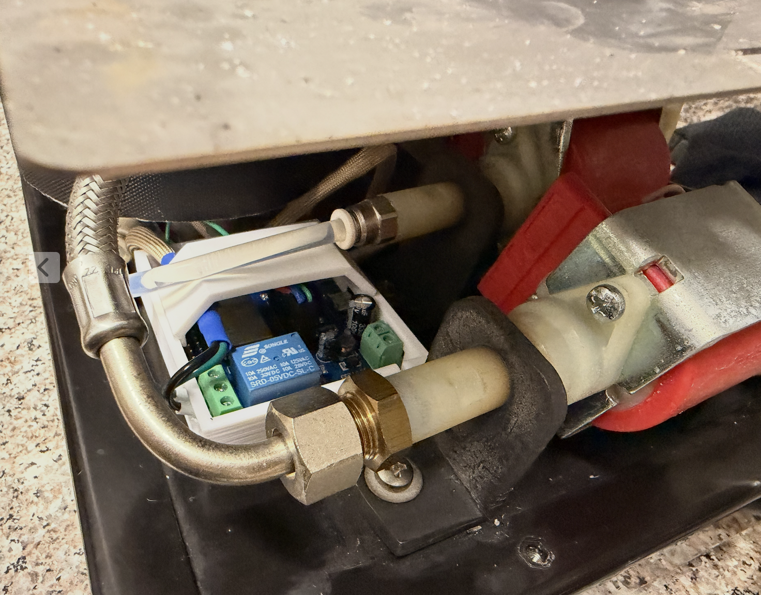
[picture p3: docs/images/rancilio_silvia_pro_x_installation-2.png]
Rancilio Silvia Pro X Installation 2

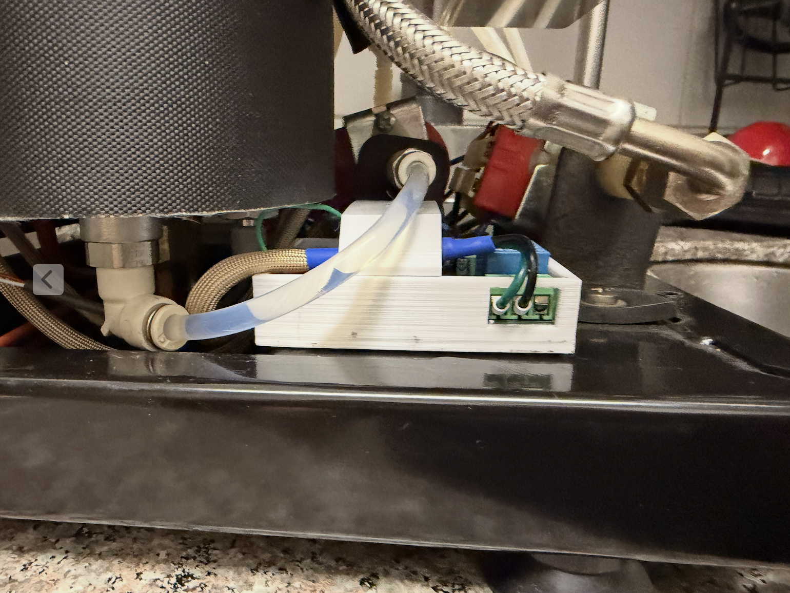
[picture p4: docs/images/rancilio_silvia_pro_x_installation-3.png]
Rancilio Silvia Pro X Installation 3


Do not use the photographs alone as a complete wiring diagram or assume compatibility from a machine name. Before connecting a machine, obtain and verify its circuit documentation and complete the applicable [bench tests](MANUAL_TEST_PLAN.md). This page cannot replace complete electrical verification.

On the Linea Micra, the intercepted brew-switch connector is labelled **CN9**.
This firmware treats that contact as the **machine circuit** — the isolated
path that makes the machine run — not as a Micra-specific name. Other machines
intercept a different brew/run circuit with the same relay contract. Other guides call this the **machine circuit** so the term also applies to
non-Micra installations.

## Parts checklist

| Part | Selection requirement |
| --- | --- |
| ESP32-S3 relay controller | Supported PSRAM variant; verify actual module, GPIO map and relay polarity against the board below. |
| Power source | Voltage, isolation, capacity, and protection verified for the actual board and machine. The repository does not define a universal machine power tap. |
| Wiring, connectors, mounting | Correct ratings, insulation, strain relief and clearance for the installation; machine-specific part numbers remain unverified. |
| Bluetooth scale | Check [model capabilities](../libraries/EspressoScaleBLE/README.md#scale-compatibility). |
| Reed/hall feedback | Recommended for momentary machines; input must be compatible with the ESP32 and isolated from the machine circuit. |
| Local sound | Optional passive buzzer; see [connection notes](#local-buzzer). |
| Independent safety barrier | A reviewed K2/heartbeat/feedback design where required; no universal K2 circuit is provided here. |
| USB data cable / console jumper | Used for installation and diagnostics; see [USB console jumper](#usb-console-jumper). |

The functional path is physical switch → ESP32 input → control policy →
isolated relay contacts → machine activation circuit. It is a signal-flow
description, not a wiring schematic. Paddle uses a maintained contact;
momentary uses press/stop pulses.

## Development board

Firmware was developed on an **ESP32-S3 1-channel relay** board (WROOM-1
**N16R8** module: 16 MB flash, 8 MB OPI PSRAM, USB-C, onboard Songle relay
with COM / NO / NC screw terminals). Product listing used for development:
[ESP32-S3 1-channel relay (AliExpress)](https://es.aliexpress.com/item/1005011880181624.html).

### Front

Front of the ESP32-S3 1-channel relay development board

### Back

Back of the ESP32-S3 1-channel relay development board

Every ESP32-S3 Relay X1 covered by this project uses the **N16R8** module. The
named `esp32-s3-relay-x1-speaker` hardware profile is the authoritative GPIO,
relay, memory, and peripheral description for the speaker-equipped assembly;
it is not a generic DevKit pinout.

The legacy build interface can still target **n8r4** (8 MB flash, 4 MB QSPI
PSRAM) for separately reviewed hardware. That architecture name does not imply
an X1 pinout or physical compatibility. Classic ESP32 and Arduino Nano ESP32
are not supported.

## 3D-printable enclosure

A simple two-part enclosure is provided for the ESP32-S3 relay development
board. Choose a matching box-and-cover pair:

- **Standard:** `OpenBrewByWeight-Box.stl` with its open/partial cover
  `OpenBrewByWeight-Cover.stl`.
- **Thick:** `OpenBrewByWeight-Box-thick.stl` with its thicker cover
  `OpenBrewByWeight-Cover-thick.stl`. This pair
  better resists deformation where the ESP32 is exposed to more heat; PETG is
  recommended.

The supplied geometry is a fit reference, not a thermal or electrical safety
rating. Choose material and mounting for measured temperatures and required
clearances; a printed case does not establish suitability inside a hot machine.

Example of the assembled, printed enclosure:

Printed Open Brew by Weight enclosure

Named wiring lives in `config/hardware/`; compile-time safety assertions remain
in `src/OpenBrewByWeightHardware.h`. Pins are **not**
editable from the Web UI.

## Default GPIOs

| Function | GPIO | Level |
| --- | ---: | --- |
| Activator (to GND) | **21** | Active **LOW** (internal pull-up; ON = GPIO LOW). Paddle or switch, depending on machine type. |
| Reed (momentary+reed builds) | **13** | Active **LOW** (internal pull-up; ON = GPIO LOW). Compile `OPEN_BREW_BY_WEIGHT_MACHINE_TYPE=2`. Override with `-DOPEN_BREW_BY_WEIGHT_REED_GPIO`. Must stay distinct from activator, relay, LED, buzzer, USB console, and safety GPIOs. |
| Onboard relay coil | **2** | Active **HIGH** (HIGH energizes the coil and closes NO) |
| Scale-connected LED | **1** | Active HIGH while a BLE scale is connected (switchable in Alerts) |
| Optional buzzer | **14** | Present on speaker builds (passive piezo, RTTTL); sounds are compiled in from the hardware profile. `-DOPEN_BREW_BY_WEIGHT_ENABLE_BUZZER=0` omits them. |
| USB console jumper | **4** | Active **LOW**. Dupont **IO4 → a GND pad you choose**. Sampled once at boot. **Do not** jumper IO4 to **EN** (that column is reset). Override with `-DOPEN_BREW_BY_WEIGHT_USB_CONSOLE_GPIO`. Must stay distinct from activator, relay, LED, buzzer, reed, and safety GPIOs. |

Optional external K2 safety (both pins or neither; no defaults, because they
depend on a reviewed board):

- `OPEN_BREW_BY_WEIGHT_SAFETY_HEARTBEAT_GPIO`
- `OPEN_BREW_BY_WEIGHT_CIRCUIT_FEEDBACK_GPIO`
- `OPEN_BREW_BY_WEIGHT_CIRCUIT_FEEDBACK_CLOSED_LEVEL` (optional; default LOW)

Compile example (GPIO overrides). Add
`-DSHOT_STOPPER_ENABLE_REMOTE_MACHINE_CONTROL=1` only for an explicit
opt-in remote-control development build; default firmware leaves start/rinse
on the physical activator:

```sh
./scripts/dev build --hardware esp32-s3-relay-x1-speaker \
  --machine la-marzocco-linea-micra \
  --flags "-DOPEN_BREW_BY_WEIGHT_SAFETY_HEARTBEAT_GPIO=16 -DOPEN_BREW_BY_WEIGHT_CIRCUIT_FEEDBACK_GPIO=17"
```

To use a different paddle, relay, LED, buzzer, or USB-console pin, add or edit
a reviewed hardware profile (or use the matching explicit `-D` override)
and rebuild. A profile must explicitly list every supported optional role;
absent hardware uses only `{ "present": false }` and has no fictitious GPIO.
Wrong pins can leave machine circuit closed or misread the paddle.

## USB console jumper

App USB CDC is **off** unless GPIO 4 is held LOW at reset (Dupont to GND),
or the firmware was compiled with `-DOPEN_BREW_BY_WEIGHT_ENABLE_JTAG=1`. Leave the
pin floating when the controller is inside the machine. Pull the Dupont
**before** installing.

- **With jumper at reset (default firmware):** `/dev/cu.usbmodem*` /
  `/dev/ttyACM*` appears; [USB serial CLI](SERIAL_CLI.md) and `monitor-idf`
  work.
- **JTAG build (`-DOPEN_BREW_BY_WEIGHT_ENABLE_JTAG=1`):** USB Serial/JTAG is on at
  boot (OpenOCD + CDC) with no jumper. Do not ship this to a machine build.
- **Without jumper, default app running:** no CDC port. Flash with
  **BOOT + RST** (ROM USB download).
- ROM download always works, jumper or not. On this board IO4 sits next to
  **EN** — never short that pair.

## Isolation (must)

- The machine circuit connects only to the relay **COM/NO** contact. Never to GND, VCC, or an
  ESP32 GPIO.
- Do not use NC as the brew path.
- Feedback, if you add it, must also be isolated. Do not join machine circuit ground to
  ESP32 ground.
- The onboard relay is **not** a certified safety barrier. A welded contact
  or a shorted driver needs a second, normally-open contact (K2) driven by an
  independent heartbeat. Without that, protection is software-only.

Verify continuity, module polarity, and that the relay stays **open** during
startup, reset, and power loss.

## Scale-connected LED

GPIO 1 is HIGH while a BLE scale is connected and **Settings → Alerts → Blue
LED while scale connected** is on. It is diagnostic only and is never part of
the machine-circuit decision.

Override at compile time with `-DOPEN_BREW_BY_WEIGHT_SCALE_CONNECTED_LED_GPIO=…`.
The pin must be output-capable and distinct from paddle, relay, buzzer,
heartbeat, and feedback.

## Local buzzer

Wire a **passive** 3.3 V piezo/speaker to `OPEN_BREW_BY_WEIGHT_BUZZER_GPIO` (default
14). The firmware drives it with PWM (RTTTL melodies), so it must be
**passive, not active**. A module with three pins — **GND**, **VCC** and
**IN** — is preferred over a loose two-wire speaker: connect GND to GND, VCC
to 3.3 V, and IN to the buzzer GPIO. For a two-wire passive piezo, connect
the marked **+** to the GPIO and the other lead to GND.

Example used: [3.3 V passive buzzer module (AliExpress)](https://es.aliexpress.com/item/1005007287329656.html).

`-DOPEN_BREW_BY_WEIGHT_ENABLE_BUZZER=0` omits the driver. See [Alerts](alerts.md) and
[Build environment](BUILD.md).

## Additional hardware used

### Reed switch (optional, strongly recommended for momentary machines)

The reed switch is optional, but is strongly recommended for momentary-button
machines such as the **Rancilio Silvia Pro X**. Without it, firmware combines
its internal state machine with scale readings to infer whether the machine is
running. With a reed switch on the solenoid, it reads the machine state
directly, which is substantially more reliable and precise.

Use it with the momentary+reed build (`OPEN_BREW_BY_WEIGHT_MACHINE_TYPE=2`); the
default input is GPIO 13, as documented in [Default GPIOs](#default-gpios).
It is generally unnecessary for latch/paddle machines such as the **Linea
Micra**.

Example used: [reed switch sensor module (AliExpress)](https://es.aliexpress.com/item/1005002797173105.html).

Related: [Disclaimer](../README.md#disclaimer), [FAQ](FAQ.md).

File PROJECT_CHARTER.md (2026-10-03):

# Project charter

Open Brew by Weight is ESP32-S3 firmware that adds local brew-by-weight to
espresso machines while preserving their physical human interface. It supports
n8r4 and n16r8 ESP32-S3 boards with PSRAM, latch/paddle machines, momentary
machines, and momentary machines with a reed or hall sensor. EspressoScaleBLE is
the local BLE scale library.

The project supplies firmware and wiring guidance, not a certified or
plug-and-play appliance. Legacy ESP32 targets, boards without PSRAM, MQTT, persistent remote-control
integrations, and guaranteed Web UI live telemetry are not project goals.
Remote shot start/rinse are disabled in default firmware; a deliberate
compile-time development opt-in exists but is not the default user workflow.

## Safety boundary

The relay is the only connection to the machine activation circuit and must be
open on startup, reset, power loss, failed boot readiness, and any safety fault.
Physical intent remains authoritative; remote activation is disabled by default.
Hard timing limits, watchdog coverage, image verification, rollback, memory
budgets, concurrency rules, and resource ownership are release constraints.

Ordinary full-firmware activations remain capped at 60 seconds. Compatibility
mode mirrors the physical paddle or switch without a duration cap; its duration
timers are not armed, while watchdog, boot/reset and feedback protections remain.
A physically admitted,
continuously supervised automatic backflush may be promoted once to a fixed
180-second ceiling measured from the original close transaction. Leaving the
active cleaning state, loss of supervision, physical release or a safety fault
opens the relay sooner. Provider semantics and physical deadlines require
qualification before release; cloud liveness is not proof of machine state.

No automated result substitutes for bench wiring inspection or required HIL and
manual evidence. See `VALIDATION.md`, `docs/HARDWARE.md`, and
`docs/MANUAL_TEST_PLAN.md` before connecting a machine.

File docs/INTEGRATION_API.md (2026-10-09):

# Integration API

This is the public LAN contract used by the Open Brew by Weight Home
Assistant integration. It is available in firmware `0.1.0` and later at
`http://<controller>/api/v1/integration`. Like the Web UI API, it is deliberately
unauthenticated and must be used only on a trusted local network. It observes
brewing and manages the single webhook destination, active preset, Home Quick
Settings, and a safe queued controller restart. It cannot start, stop, rinse,
or directly actuate the machine.

## Common rules

- Requests and responses use `application/json`; request bodies are limited to
  2,048 bytes and response collections to `MAX_SHOT_PRESETS` items.
- Success responses contain `apiVersion: 1`, except the integration snapshot,
  which uses `apiVersion: 2` and `minimumClientApiVersion: 2` for its unified
  `lastShot` contract. Errors use
  `{"error":"STABLE_CODE","message":"English diagnostic"}`.
- All routes are open on the trusted LAN and use no token, pairing window, or
  authorization header.
- Durable mutations return `202` and a `requestId`; this acknowledges only that
  the existing control queue accepted the operation. Poll the request-status
  route until it reports `PERSISTED`. A mutation is not successful before that
  state. Clients time out after 10 seconds and may retry idempotent operations.
- Restart is the exception: its accepted response is final because the
  controller intentionally becomes unreachable. Do not poll its request ID.
- Webhook, preset, and Quick Settings mutations retain the firmware's existing
  safe-state gate and are rejected while a shot cycle is active. Restart is
  accepted during a shot but the existing control owner defers it until idle.

## Status and error codes

| HTTP | Code | Meaning |
| --- | --- | --- |
| 400 | `INVALID_REQUEST` | Malformed JSON, field, identifier, or bound |
| 404 | `PRESET_NOT_FOUND` | Stable preset ID does not exist |
| 409 | `CONFIG_LOCKED_DURING_ACTIVE_CYCLE` | Existing firmware safety gate is closed |
| 409 | `STALE_REVISION` | Quick Settings changed since the caller's snapshot |
| 409 | `REQUEST_BUSY` | Another persistent request owns the queue/staging slot |
| 413 | `CONTENT_TOO_LARGE` | Body exceeds the fixed request buffer |
| 500 | `PERSISTENCE_FAILED` | The durable write failed |
| 503 | `CONTROL_QUEUE_FULL` | The bounded control queue could not accept the command |
| 503 | `WEBHOOK_UNAVAILABLE` | Test event could not be queued or delivered |

## Routes

### `GET /api/v1/integration`

Returns identity, compatibility, current shot state, the newest recorded shot,
preset revision, and the complete Quick Settings snapshot.

```json
{
  "apiVersion": 2,
  "minimumClientApiVersion": 2,
  "deviceId": "AA:BB:CC:DD:EE:FF",
  "wifiMac": "AA:BB:CC:DD:EE:FF",
  "bluetoothMac": "AA:BB:CC:DD:EE:10",
  "manufacturer": "Open Brew by Weight",
  "model": "Open Brew by Weight",
  "firmwareVersion": "0.1.0",
  "capabilities": ["webhook_v1", "preset_select_v1", "quick_settings_v1", "restart_v1", "stored_shots_v1"],
  "shotState": "idle",
  "bootId": 123,
  "activePresetId": 2,
  "presetRevision": 19,
  "quickSettings": {
    "revision": 19,
    "activePresetId": 2,
    "brewByWeight": true,
    "noScaleBbwMode": "warn_once",
    "autoToManualGuardEnabled": true,
    "slowExtractionGuardEnabled": true,
    "fastExtractionGuardEnabled": true,
    "avoidAccidentalTouchEnabled": true,
    "cupProtectionEnabled": true
  },
  "lastShot": null,
  "lastActivation": null,
  "stats": {"shotCount": 0, "totalDurationS": 0, "avgDurationS": null, "avgYieldG": null, "avgErrorPct": null, "avgFlowGps": null, "shotsPerDay": null, "durationsS": []}
}
```

`lastShot` is nullable and describes the newest qualifying record in shot
history: a confirmed non-rinse cycle longer than 12 seconds with a valid final
yield over 2 g. Other completed activations appear only in `lastActivation`.
When present, `lastShot` contains
`cycleId`, `uptimeMs`, `durationMs`, `targetWeightG`, `presetId`, `presetName`,
`shotType`, `stopDetail`, `savePending`, and the optional `firstDropMs`, `weightG`,
`averageFlowGps`, and `rating` fields defined by the webhook contract. When the
controller has a valid clock at shot completion, it also includes
`endedAtUnixSec` (UTC) and `endedAtLocalSec`; otherwise both are absent.
The local value uses the saved time zone's offset at shot completion and stays
fixed if the zone changes later. Consumers should use `endedAtUnixSec` for an
unambiguous instant.
`savePending` is true while the deferred flash write still needs confirmation;
if saving fails, the record remains in RAM for a retry. Firmware with the
earlier v1 snapshot instead had distinct `lastShot` and `lastGoodShot` fields.
Clients that require that older meaning should check `apiVersion` before using
the new field.

`lastActivation` mirrors the newest activation-history record (the Web UI
History page). It is null before the first activation after a full data reset
and otherwise carries `id`, `type` (`shot`, `rinse`, `other`, `backflush`, `power_on`, or
`no_scale_guard_aborted`), `durationS`, `hasWallTime`, `endedAtUnixSec`, and
`endedAtLocalSec`.

`backflush` identifies a confirmed automatic-cleaning activation, including an
interrupted one. Duration measures electrical activation, not certified program
completion. It does not update shot statistics. The additive type preserves
the existing history record layout and schema.

`stats` carries the rolling aggregate shown at the top of the Web
UI Stats page: `shotCount`, `totalDurationS`, `avgDurationS`, `avgYieldG`,
`avgErrorPct`, `avgFlowGps`, `shotsPerDay`, and `durationsS` for the duration
chart. The window is the newest ten eligible shot records, including manual and
timer-only endings. `avgErrorPct` is the mean absolute percentage miss of only
normal BBW target cuts in that window. Unavailable averages are `null`.
The controller derives these values from RAM; the Web UI streams the same
object over its data WebSocket, and this payload carries it under `stats`,
alongside `savePending`.

`shotState` is `idle` or `brewing`. `wifiMac` and `bluetoothMac` repeat the
station interface addresses as upper-case `AA:BB:CC:DD:EE:FF` strings; the
Bluetooth address uses the controller's Bluetooth MAC base. Receivers may
surface them as device connections but must keep using `deviceId` as the
stable identity.

### `GET /api/v1/integration/request`

Returns the most recent durable command as
`{"apiVersion":1,"requestId":17,"state":"PERSISTED"}`. Compare its ID with
the mutation response. Valid terminal states are `PERSISTED`, `FAILED`, and
`CANCELED`.

### `GET /api/v1/integration/webhook`

Returns `enabled`, `url`, `brewState`, `firstDrop`, `end`, `presetChanges`, and
`deferDuringShot`. When that flag is true, queued requests wait while a shot is
active; a request that already started is never cancelled.

### `PUT /api/v1/integration/webhook`

Requires all webhook fields. The URL must be a bounded `http://` URL without
embedded credentials. Repeating the same request is successful and does not
create another destination.

### `POST /api/v1/integration/webhook/test`

Accepts `{"correlationId":"<1-64 URL-safe>"}` and queues the matching `test`
event. The event echoes `correlationId` so Home Assistant can prove that its
newly registered receiver is reachable.

### `GET /api/v1/integration/presets`

Returns a bounded snapshot:

```json
{"apiVersion":1,"activeId":2,"revision":19,"items":[
  {"id":2,"name":"Double","isFactory":true},
  {"id":1,"name":"Single","isFactory":true}
]}
```

Preset IDs are stable while an item exists and names are unique.

### `PUT /api/v1/integration/presets/active`

Requires `{"id":2}`. The `202` response identifies the existing persistent
command. After it reaches `PERSISTED`, read the preset snapshot for the
authoritative active value. A failed or timed-out write never reports the
candidate as confirmed.

### `PUT /api/v1/integration/quick-settings`

Requires `baseRevision` plus exactly one setting. Boolean settings are
`brewByWeight`, `autoToManualGuardEnabled`, `slowExtractionGuardEnabled`,
`fastExtractionGuardEnabled`, `avoidAccidentalTouchEnabled`, and
`cupProtectionEnabled`; `noScaleBbwMode` accepts `off`, `warn_once`, or
`require_scale`. Extra, duplicate, or incorrectly typed fields are rejected.

`brewByWeight` changes the current session override, `noScaleBbwMode` changes
the shared machine policy, and the five guard values change only the active
preset. The durable confirmation and authoritative-refresh rules are identical
to active-preset selection.

### `POST /api/v1/integration/restart`

Requires the exact empty object `{}`. A `202` response means the existing safe
restart path accepted the request. During an extraction it waits for the cycle
to end; it never closes the relay or resumes a cycle after boot. This trusted-
LAN route exposes no machine actuation counterpart.

### `POST /api/v1/diagnostic/scale-profile`

Starts, stops, or deletes the manual scale profile capture. Requires the
exclusive Web UI claim like every owned API route. The body is
`{"action":"start"}` or `{"action":"stop"}` or `{"action":"delete"}`; replies
`202 Accepted` with a request id that follows the common acknowledgement
rules. Bounded state (including `state`, `persistence`, counts, `stopReason`,
`lostCount`, and `canStart`/`canStop`/`canDelete`/`canDownload`) is reported
as `scaleProfile` in the diagnostic status document.

Capture has no duration cutoff: it stops on explicit request or when all
ordinary record slots are occupied, preserving one slot for the closing event.
The existing numeric `durationLimitMs` field is deprecated and is always `0`
(no limit). `elapsedMs` reports elapsed capture time independently of capacity.

| Status field | Meaning |
| --- | --- |
| `recordCount` / `recordCapacity` | Accepted records in the current or saved capture / total payload slots (8,192). Empty/preparing states expose zero current records. |
| `recordBytes` | Fixed stored record size, 32 bytes; downloaded text size is unrelated. |
| `reservedRecords` | One terminal slot while recording, zero otherwise. Capacity used is `(recordCount + reservedRecords) / recordCapacity`. |
| `estimatedRemainingMs` | Smoothed estimate until capture capacity fills, or JSON `null` until enough data arrives, after a sustained stall, or outside recording. Full captures report zero. It never acts as a deadline. |

The estimate is maintained by the firmware independently of status polling. It
uses all accepted records, samples growth about once per second, and smooths
the rate with a five-second exponential time constant. Initialization requires
at least five seconds and ten records after the initial state snapshot; five
seconds without progress invalidates it. A new session resets the estimate.
`persistence` remains the authority for pending/saving/saved/failed state:
recorded bytes are not claimed as durable before the save completes.

### `GET /api/v1/diagnostic/scale-profile/download`

Streams the most recent completed capture as a chunked `text/plain`
attachment (`Content-Disposition: attachment`,
`Cache-Control: no-store`). Disabled while a capture is recording; a trace
that stopped but has not finished saving downloads from memory and is labeled
accordingly. Concurrent Start/Delete are refused while the download streams.

The trace retains the 32-byte record layout and schema version 1; new event IDs
are appended, preserving the meaning of saved records. `STATE_CHANGED` rows
contain a named scalar signal, `from`, `to`, originating `capture` sequence,
and connection generation. `from=initial` means the first control-owner
observation in this capture, not a transition from an assumed default.
Control observations are contiguous batches; their timestamps are observation
times, independently of the initial header snapshot. No initial observations
means control was not observed before capture stopped. Unchanged signals are
omitted; a new connection generation renews the observations.

New `PROFILE_START` rows state `limit=capacity`; historical `maxMs` and timeout
overrun rows remain readable. Durations and exported relative times can exceed
the 32-bit millisecond rollover: ordinal bits 0–13 retain append order and bits
14–31 contain the high word of the record time. Header `reserved[0]` contains
the high word of `durationMs`. Legacy records and headers have zero extension
bits; their interpretation is unchanged. Readers that decode binary records
must combine these words before sorting or displaying long captures. Old
firmware retains its original 32-bit time display for such long captures.

Signals cover cup presence, settling and removal qualification, reference/mass
validity, tare eligibility/presentation/reasons, request and placement IDs,
accessory settling, stream and weight control, retare/baseline waiting, first
flow/touch phases, brew protection, scale-loss guard, and pending finalization.
`IDLE_STATUS` uses the same decision rule as Web status, with readable
`waiting_for_settle` and `ready_for_cup` names for Web `empty` and `ready`.
Other booleans use 0/1. `*_CG` values are signed centigrams (unknown references
are rendered `unknown`); `*_MS` values are milliseconds. Effective tare/cup
thresholds and timing settings are emitted initially and when they change.
Raw `WEIGHT` rows retain the received floating-point weight precision.

`TARE_PHASE` preserves queued/writing/succeeded/failed command transitions even
when they occur between control observations. Its ID belongs to the idle-tare
request namespace; `boundary` is a capture sequence. `TARE_REJECTED` identifies
the placement in `context`; `CUP_QUALIFICATION_RESET` uses context 0 for empty
pan, 1 for cup placement, and 2 for accessory settling. Their `pkt` is the
control packet sequence. `CUP_RESET` is a logical reset, not proof of physical
removal. `FINALIZE_CANCELLED` distinguishes cup continuity, a new cycle, and
rinse. Existing shot-end reasons continue to describe guard stop outcomes.

For correlation, follow `IDLE_REQUEST_ID`/`IDLE_PLACEMENT_ID`/`IDLE_ORIGIN` for
idle tare, and `SHOT_TARE_REQUEST_ID`/`RETARE_REQUEST_ID`/`CYCLE_ID` for shot
tare. Do not equate idle request IDs with shot request IDs, or packet sequences
with capture sequences. A zero sequence means no specific sample is identified
(for example, a timer-only observation). Transport success does not establish
physical zero; baseline confirmation and timeout remain separate events.
For existing `TARE_REQUEST` rows, `seq` is the qualifying control packet for
idle/accessory tare and zero for shot/manual requests. A return from writing
to queued in `TARE_PHASE` means the worker deferred the write; it is not success.
Internal per-sample counters, UI rendering, unrelated network state, and
unreported physical scale-button actions are outside this trace's scope.

The capture still reserves a terminal record and reports overflow/loss. Its
per-signal deduplication cache is bounded PSRAM, reset for every capture;
no new partition, endpoint, or control owner is introduced. Older captures
remain readable; unknown event IDs render their numeric payload safely.

## Web UI record API

Neither record page has a REST read: Stats and History both subscribe over
the owned WebSocket (see [History live updates](#history-live-updates) and
[Stats live updates](#stats-live-updates)). Both surfaces require the active
`X-WebUI-Client` obtained from `POST /api/v1/ui/claim`. They are separate from
the public integration routes described above. Mutations stay confirmed REST
commands: `POST /api/v1/stats/clear|delete|rate`,
`POST /api/v1/history/clear|delete`.

Stats and History frames both carry `boot`, `total`, `offset`, `limit`,
`hasMore`, and a small `ui` object (snapshot frames only). Stats frames also
carry `stats` (the firmware-computed aggregate) and `rows` — the same row
fields used for the table and CSV export, with each row's curve arrays embedded at the
top level; pages larger than the frame budget continue across frames with
`rowBase` and `more` until a terminating frame. History frames carry
`records`. Paging and sorting parameters are unchanged: `offset`, `limit`, and `dir` (`asc` or `desc`), plus
`sort` (`date` or `rating`) for Stats. The page sizes used by the browser are
ten shots and twenty activations.

The browser derives each shot's error from its displayed yield and goal;
WS rows omit `errorG` and `errorPct`. Per-shot `bootId` remains part of the
row identity. History records carry `hasWallTime` and both timestamps;
the unused `hasWeight` flag is omitted. These owned Web UI projections
ship with the embedded frontend and do not change the public integration API.

`ui` contains `firmwareVersion`, `configMutable`, `webUiOverrideActive`,
`compatibilityMode`, `development`, `machineType`, `machineIntegration`,
`timeUtcSec`, `snapshotStale`, `connections`, and `lastCommand` (`requestId`,
`state`). Its `config` contains
`revision`, `timezoneId`, `appliedTimezoneOffsetMinutes`,
`timezoneAutomatic`, and `timezoneInitialized`. These fields update shared
UI behavior, relative dates, and automatic timezone synchronization without
fetching Home's scale, cup, preset, or extraction state. The browser validates
and applies this state before displaying the records; it arrives with the
snapshot frames of both record streams. Accepted WebSocket ops (claim, bind,
activity, and the view subscriptions) retain the confirmation of pending
Wi-Fi settings on a station connection.

Home's live stream, the other Web UI page status responses, and the record-page `ui` envelope include
`connections`: `wifiConnected` and `bluetoothConnected` are booleans;
`wifiLevel` and `bluetoothLevel` are firmware-calculated levels:
`1` weak, `2` medium, `3` strong, or `null` when unavailable. The connection
booleans determine whether to display disconnected, regardless of a cached level.
`wifiName` is the connected station SSID; `bluetoothName` is the connected
scale's saved friendly name, falling back to its recognized model name, or to
its advertised BLE name when the model is unknown. Names
are empty when the link is disconnected or no matching scale identity is
available. The browser hides these identities when the snapshot is stale.
Wi-Fi refers to the controller's station link, and Bluetooth refers to its scale
link. Valid readings range from −128 through 0 dBm. The header uses three
display levels: weak below −80 dBm, medium from −80 to below −60 dBm, and
strong at −60 dBm or above. A disconnected link takes
precedence over any reading. Stale control snapshots or missing measurements
show unavailable signal quality. These display fields add no radio queries or
extra polling requests and do not change the public integration endpoints.

### Home live updates

The claimed browser binds the existing WebSocket at `/api/v1/ui/ui-stream`
with `{"op":"bind","client":"<claimed X-WebUI-Client>"}`. Home receives an
initial snapshot and then field changes, without periodic REST status requests.
The firmware compares the published state at most every 100 ms while a shot is
running, and at most every 250 ms otherwise, while a browser is connected.
Unchanged displayed values produce no Home data frames. Weight
and timer are inspected only while the scale is connected, at the displayed
precision (0.1 g and 0.1 s); unavailable readings become `null` once.

Home frames have `v: 1`, `type: "home"`, `boot`, `snapshot`, and `changes`.
The header uses the firmware-calculated signal levels described above.
RSSI changes within a level produce no signal delta; raw RSSI remains
available in Diagnostics. The header popups display level names without dBm.
The initial snapshot supplies the complete Home state; subsequent `changes`
objects contain only changed paths, such as `scale.timerMs` or
`lineaMicra.websocket.cleaning`. Objects such as `presets` are replaced as a
unit when they change. Reliable, ordered WebSocket delivery applies these
scalar assignments in order. The shot card and curve retain their independent
sequence/base and cursor contract on the same socket. Equipment updates do not
resend an unchanged shot card or curve. Commands continue to use the existing
HTTP endpoints and ownership checks.

Micra firmware streams an informational boiler-readiness layer on the same
frames: `lineaMicra.readiness` (the derived rollup: `off`, `warming_up`,
`waiting_for_steam`, `ready`, `needs_water`, or `unknown`),
`lineaMicra.boiler.coffee.state` and `lineaMicra.boiler.steam.state`, and each
boiler's `readyAtUtcSec` estimate. `readyAtUtcSec` is an absolute UTC second
timestamp (0 when the machine gave no estimate), and the browser derives the
ticking countdown locally, so a stable estimate emits no frames. Readiness is
never evidence for control; power stays ON/OFF-only.

Reconnect and `{"op":"resync"}` request fresh snapshots; the resync op also
forces a fresh History snapshot for subscribed sessions. Ownership takeover
closes the previous socket with code 4001. Bounded `activity`/`alive` control
messages every 20 seconds detect a lost connection and preserve existing power
activity behavior; they do not request or repeat Home data. Clock synchronization
supplies a new time anchor; the browser advances relative time locally.
`GET /api/v1/status/home` no longer exists: navigation visibility
(`diagnosticPageVisible`, `compatibilityMode`) is carried by the Home stream
itself and applied on every view, and the browser no longer probes a status
route when entering Stats, History, or Diagnostic. Settings, Admin, record
status, and the public integration API keep their existing REST contracts;
the Diagnostic page is WebSocket-only and is described next.

### Diagnostic live updates

The Diagnostic page subscribes on the same owned socket with
`{"op":"diagnostic","on":true}` when the view appears and unsubscribes on
every navigation. The first frame after subscribing is a snapshot; later
frames are `changes` deltas merged in order, exactly like Home. The
`{"op":"resync"}` message re-arms a fresh snapshot, and `GET /api/v1/log`
and `/api/v1/status/diagnostic` no longer exist.

Diagnostic frames have `v: 1`, `type: "diagnostic"`, `boot`, `snapshot`, and
`changes`. A field is sent only when its value changed since it was last
sent. An unchanged projection emits no frame; displayed ages, uptime,
traffic and other live measurements can still change on an otherwise idle device.
Event-driven state (control, safety, guards, maintenance, crash count, NTP
and Wi-Fi link state, machine integration) is evaluated on every dispatch
tick and lands within one tick (at most 100 ms during a shot, 250 ms
otherwise). Countdowns and ages are quantized to whole seconds (the no-scale
cooldown to whole minutes) so a ticking value costs at most one small frame
per second. Sampled telemetry (heap and CPU health, hardware monitor, NVS
statistics, steady-state Wi-Fi RSSI and signal quality, task profiler, scale
profiler, machine-integration traffic counters) shares a four-second
evaluation gate, so its producers cost no more than the retired status poll.
NTP synchronization age/retry countdowns and raw Micra subscription/reconnect
counters are not sent to this view. The task-profiler projection includes
the displayed CPU, stack and loop-gap measurements; the full debug export
retains additional capture and execution statistics. Scale-profile action
availability and errors remain in the live projection, while internal
session and storage metadata remain owned by the profiler.
A snapshot arrives in stages: the core frame carries the live projection and
the following frames deliver the heavier sections; the page renders each
section as it lands. The wall clock is not streamed: the page renders UTC and
local time from the Home stream's time anchor and ticks locally.

The serial log subscribes on the same socket with
`{"op":"log","on":true,"after":<last rendered sequence>}` while the page is
shown and unsubscribes on navigation. Log frames have `v: 1`, `type: "log"`,
the display payload (`bootId`, `historyOverwritten`,
`missedEvents`, `serialDropped`, `hasMore`,
`cursorInvalid`, `events`), and are pushed when the log ring advances; a
backlog pages across dispatches with `hasMore`, and an invalidated cursor
refills the view from the oldest retained event without a client round trip.
Each event carries `sequence`, `atMs`, `wallSec`, `localSec`, `level`,
`category` and the formatted `message`; internal event codes and arguments
are retained in the firmware rather than repeated on the wire.

Commands from the Diagnostic page (log levels, profiler start and stop, loop
and scale-gap resets, reset-history clearing, machine-integration refresh)
keep their HTTP endpoints; their results reach the page through the stream's
`lastCommand` and configuration revision fields, so no status polling backs
them.

The former `/api/v1/shots` route family was renamed to `/api/v1/stats` and its
GET read has since moved to the owned WebSocket: external Web UI API callers
must use the stream described below for reads and keep the POST URLs
`/api/v1/stats/clear`, `/api/v1/stats/delete`, and `/api/v1/stats/rate`
(request bodies and mutation safety checks are unchanged).
The public `/api/v1/integration` endpoints are unchanged.

Stats shot records and Home's WebSocket `curve` carry paired `wCg` and `wAtMs`
arrays: accepted centigram weights and their elapsed reception times in integer
milliseconds, with up to 1201 observations. Use those times instead of the
removed shared `wDtS` interval. `wBreakBefore` lists zero-based indices that
start new continuous segments; `wTruncated` identifies an incomplete capture.
Curve event fields such as `dropS` and `endS` remain seconds and retain three
decimal places. Events are annotations, not extra received observations.
The [shot-history export contract](features/shot-history.md#read-a-result)
describes the corresponding ordinal CSV sample groups.

### History live updates

The History page rides the same owned WebSocket as Home. Entering the view
subscribes with the page window:

```json
{"op":"history","on":true,"offset":0,"limit":20,"dir":"desc"}
```

The session keeps this standing window. Scrolling to the page sentinel sends a
one-shot append fetch for the next window without disturbing the subscription:

```json
{"op":"history","on":true,"fetch":true,"offset":20}
```

Leaving the view no longer unsubscribes it: the browser keeps the History
window standing for the whole UI session, so arriving records update the page
even while another view is open. Opening History with that live data paints
straight from the cached page, and the page a URL load starts on is fetched
first; any record page still not standing is subscribed in the background as
soon as the first view finishes loading. After a reconnect or a tab
refocus, the browser replays the subscription and resyncs, so the first open
still starts from a fresh snapshot. Every accepted op forces the next frame to
be a full snapshot of the requested window.

History frames have `v: 1`, `type: "history"`, `boot`, `snapshot`, `epoch`,
the `ui` object (snapshot frames only), `total`, `offset`, `limit`, `hasMore`,
and `records`. Each record carries `id`, `type`, `durationS`, `hasWallTime`,
`endedAtUnixSec`, and `endedAtLocalSec`. A store epoch and a fingerprint over the finished frame
suppress sends while the page is unchanged, the same no-change contract as the
Home delta: an untouched activation log produces no frames. Appends, single
deletes, and clears move the epoch, so the standing subscription pushes the
updated page without any browser request; clearing and deleting remain the
confirmed REST commands above.

### Stats live updates

The Stats page uses the same owned WebSocket. Entering the view subscribes
with the page window:

```json
{"op":"stats","on":true,"offset":0,"limit":10,"sort":"date","dir":"desc"}
```

Scrolling to the page sentinel sends a one-shot fetch for the next window,
and the CSV export asks for its own export window — always 100 rows,
newest-first by date, regardless of the on-screen sort:

```json
{"op":"stats","on":true,"fetch":true,"offset":20}
{"op":"stats","on":true,"fetch":true,"offset":0,"limit":100,"sort":"date","dir":"desc"}
```

Leaving the view no longer unsubscribes it: the Stats window also stays
standing for the whole UI session, refreshes in the background while any view
is open, and re-opens paint straight from the cached rows. After a reconnect
or a tab refocus, the browser replays the subscription and resyncs, and every
accepted op forces the next page to start from a full snapshot.

Stats frames have `v: 1`, `type: "stats"`, `boot`, `snapshot`, `epoch`,
`seq`, the `ui` object and the `stats` aggregate (first frame of a page
only), `total`, `offset`, `limit`, `hasMore`, `rows`, `rowBase`, and `more`.
Each row retains its own `bootId` and curve arrays; row errors are calculated
from the displayed yield by the browser. Because full curves can exceed one
frame, a page is emitted under a ~20 KiB frame budget: the first frame ends with `more: true` and a
continuation frame resumes at its `rowBase`; the browser buffers partial
pages and applies them whole when a frame ends with `more: false`. A store
epoch and a fingerprint (window, aggregate, and per-row id, rating, and
curve hashes) suppress pages while nothing changed — rating a shot, saving,
deleting, or clearing moves the epoch, so the standing subscription pushes
the updated page without any browser request. The export window streams the
requested rows once without touching the subscribed view state. The server
refreshes its cached records when the store epoch, sort field, or sort direction
changes; subsequent frames reuse that snapshot. This preserves chronological
CSV order after browsing by rating without repeated store captures per frame.

## Linea Micra Web API

Micra-compiled firmware exposes `POST /api/v1/machine/linea-micra` to the
claimed Web UI. It accepts one strict `action`: `connect`, `select`, `save`,
`refresh`, or `disconnect`. `connect` requires only `username` and `password`
and is rejected unless STA is connected and the setup AP is closed. It queues
cloud authentication and account-machine discovery but does not persist or
enable an account. `select` requires a `serial` from the latest discovery plus
the independent `applyTemperature`, `observeState`, and
`recognizeWakeGesture` booleans; it persists the
account credentials, installation key, and chosen machine through the normal
single-writer command path. `select` and `save` also carry the `powerOnWithScale`
and `shutdownWithScale` machine-link booleans with `shutdownGraceSeconds`,
and the `scaleOffWithMachine` scale-link boolean. `select` and `save` optionally accept `connectionType` as exactly `websocket`
or `api`; missing retains the saved preference. Null, wrong types, unknown
values and use with any other action are rejected. WebSocket is the default.
`save` updates those options for an already selected machine. `refresh` and `disconnect` accept no additional fields;
disconnect erases durable credentials/selection and the RAM session. Unknown,
duplicate, or action-inappropriate fields are rejected. Accepted commands
return `202`.

Settings and diagnostic status include a Micra subtree only in Micra firmware.
It reports whether an account is configured, selected name/serial, option flags,
request phase/error, ON/OFF/UNKNOWN power state, raw observed mode, evidence
quality, optimistic-ON and optimistic-OFF provenance, sample age/freshness,
selected target
temperature, STA/AP/shot gates,
last HTTP/transport status, and the bounded machine list returned while
connecting. The saved account email is visible in Settings and Diagnostics; password,
installation private key, access token and refresh token are never returned. `refresh` is read-only and requires a selected
machine; none of these fields authorizes machine actuation.

The subtree also reports `connectionType`. Diagnostic status alone includes
`lineaMicra.websocket`: socket lifecycle/reason/epoch, subscription and machine
connectivity, genuine evidence timestamps, payload byte counters, fixed 1s/60s
rates, retry/stop/publication latency, cleaning availability and memory metrics.
Diagnostic status also carries the boiler detail beyond the Home projection:
`lineaMicra.boiler.coffee.targetDeciC`, `lineaMicra.boiler.steam.level`
(`level_1`–`level_3`), and a whole-second `lineaMicra.boiler.sampleAgeMs`.
`cloudCall` remains the last HTTP call. Cleaning never changes control state.
Payload byte totals use 64-bit counters and include positive partial sends.
Rate windows use the 64-bit monotonic clock, independently of millisecond
timestamp rollover; these counters exclude TCP/TLS framing and radio traffic.
Connect/stop free/largest deltas refer to internal heap; retained workspace bytes
refer to PSRAM. Cleaning age/source hints are hidden when observation is disabled
or API is selected.
Generic diagnostic `outboundPause` exposes acquisition generation/reason,
concurrent `scaleSetup`, `bleQuiet`, `shot` and `maintenance` gates, and per-client
applicability and owner completion/latency. `requested` and `completed` refer to
the acquisition generation; completion excludes residual DNS work.
Webhook status distinguishes `lastDispatched` and `lastDeliveryUnknown`.

## Webhook version 1

All messages are POSTed as bounded JSON. Common fields are `schemaVersion: 1`,
`event`, `deviceId`, `bootId`, `cycleId`, `uptimeMs`, `timestamp`, and
`sentAtUptimeMs`. `brew_state`, `first_drop`, and `end` contain both `presetId`
and the name captured at cycle start in `presetName`.

`presets_changed` is emitted only after confirmed persistent preset mutation
and contains `activeId`, monotonic `revision`, and the same bounded `items`
array as the presets route. It is disabled for migrated webhook configurations
and enabled explicitly by the native integration.

`quick_settings_changed` is likewise emitted only after persistence. Its complete
Quick Settings snapshot is flat in the event envelope:

```json
{
  "schemaVersion": 1,
  "event": "quick_settings_changed",
  "deviceId": "AA:BB:CC:DD:EE:FF",
  "bootId": 123,
  "cycleId": 0,
  "uptimeMs": 930100,
  "timestamp": 1767225619,
  "sentAtUptimeMs": 930110,
  "revision": 20,
  "activePresetId": 2,
  "brewByWeight": true,
  "noScaleBbwMode": "warn_once",
  "autoToManualGuardEnabled": true,
  "slowExtractionGuardEnabled": true,
  "fastExtractionGuardEnabled": false,
  "avoidAccidentalTouchEnabled": true,
  "cupProtectionEnabled": true
}
```

`controller_started` is one best-effort boot hint containing controller identity,
`bootId`, and the current revision; receivers use it to perform one full REST
reconciliation. The existing
`presetChanges` subscription bit gates all integration-state events:
`presets_changed`, `quick_settings_changed`, `controller_started`, and
`integration_history_end`.

`integration_history_end` mirrors the newest activation-history record
(shot, rinse, other, power on, or a no-scale guard abort) and carries `id`,
`type`, `durationS`, `hasWallTime`, `endedAtUnixSec`, and `endedAtLocalSec` —
the same shape as the snapshot's `lastActivation`. It is emitted only after
the activation record is confirmed in history, including after controller
restart when the persisted `presetChanges` subscription remains enabled. A
receiver that misses it can
recover the value at the next reconciliation.

Receivers deduplicate by `(deviceId, bootId, cycleId, event, uptimeMs)`, reject
older events for the same boot, and refresh the REST snapshot when configuration
or preset revisions skip. Numeric shot fields must be finite and non-negative. Supported
shot types are `auto`, `timer_only`, and `manual`; supported stop details are
`normal_target`, `extended_max_weight`, `extended_min_time`, `auto_to_manual`,
`slow_max_time`, `slow_min_weight`, `cup_removed`, `activator`, `web_stop`,
`web_heartbeat`, `physical_override`, `hard_limit`, `wall_limit`,
`relay_safety`, `weight_anomaly`, `touch_weight_fallback`, and `other`. `prediction` is accepted as a
legacy alias for `other`.
`touch_weight_fallback` identifies a stop after sustained above-threshold
readings while accidental-touch protection blocks the normal cut. REST `lastShot`,
end webhooks and local history preserve this same value. Update strict receivers,
including the Home Assistant integration, before installing firmware that emits
it; older integration versions reject unknown stop details.

The webhook ID protects only the Home Assistant receiving endpoint; it does not
authenticate controller API calls. Do not log or include it in diagnostics.
Removing a Home Assistant entry conditionally clears only a callback whose
exact URL still belongs to that entry.

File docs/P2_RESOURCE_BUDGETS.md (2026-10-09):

# Resource budgets

This file versions the firmware's quantitative resource limits. The P2 filename
is retained for existing tool and evidence references. It is
an implementation contract, not a substitute for target/HIL evidence.

## Firmware image and static regions

`config/resource-baselines.json` records the current n16r8 `-O2` baseline and
the historical n8r4 `-Os` baseline. Every test or review that measures these
budgets must compile with the
`--development` profile; it enables the admin unlock and the USB Serial/JTAG
console and gives a reproducible comparison profile. This is enforced, not
just prose: the R2/R3 validation gate compiles every supported profile pair
with `--development` (FIRMWARE_BUDGET_OPTIONS in scripts/dev), a tooling test
pins that composition for both risk levels, and any other build profile makes
the resource verifier print "budget evidence requires a --development build"
instead of comparing baselines. Comparisons must use the
same hardware and machine profiles and the same profile on both sides. Every
supported build emits `size.json` from the linker map and
records image bytes, total linked bytes, DIRAM, flash code, and flash rodata.
The verifier requires valid measurements for all five metrics at every
optimization level.
The versioned n16r8 baseline comparisons apply to `--development -O2` builds;
the n8r4 comparisons retain their historical `--development -Os` scope. Normal
release builds and other optimization levels retain the OTA-slot, external-BSS,
and internal-placement checks. The development and release Web UIs differ, so
the development image is not always the larger one.
Small reviewed growth allowances catch regressions without coupling unrelated
toolchain padding to an exact byte count; raising a baseline or allowance
requires explicit architecture and resource review.
The current baselines were measured with ESP-IDF 6.1, its GCC 15.2 toolchain,
and the qualified `CONFIG_FREERTOS_IN_IRAM=y` build profile.

The n16r8 flash baseline represents the largest reviewed supported profile:
the Linea Micra cloud build with WebSocket observation, on
`esp32-s3-relay-x1-speaker` at `8d09ecc7`. The clean development profile with
USB Serial/JTAG measures 2,273,760 image bytes, 2,273,647 total linked bytes,
1,515,100 flash-code bytes and 587,352 rodata bytes. The versioned growth
allowances remain 32,768 and 16,384 bytes for flash code and rodata; the
image and total linked allowances were raised from 38,640 and 38,628 bytes to
38,768 and 38,756 bytes for the reviewed frosted-glass sliding navigation
pill assets (about 250 compressed bytes, partly absorbed by flash
compression), again to 43,520 and 43,508 bytes for the Stats duration and
gram-weight metric icons and the view-scoped Diagnostic WebSocket stream
(measured 2,317,248 image bytes: the icons consumed the remaining headroom
and the Diagnostic stream adds about 4.2 KB — a bounded per-field diagnostic
projection with per-session fingerprints, the socket subscription client, and
the shared live section renderer, with flash code and rodata growth staying
inside their separate allowances and DIRAM growing 528 bytes for two
fingerprint slots), and once more to 43,904 and 43,896 bytes when the
Diagnostic stream gained its Scale weight field (measured 2,317,600 image
bytes through the validation gate's machine-type-specific Web UI pipeline;
the two follow-up measurements differ by 48 bytes of asset/toolchain
padding for the same source), and to 44,016 and 44,008 bytes when the Home
shot card gained its no-scale timer layout (measured 2,317,712 image bytes;
the card's new `scaleAvailable` field plus the slightly larger localized
runtime account for about 110 bytes after flash compression). The browser-local
no-scale timer raises those allowances by another 320 bytes, to 44,336 and
44,328 bytes. The reference development build measured 2,318,032 image bytes
and 2,317,919 linked bytes. This change adds browser clock state and animation
only: DIRAM remains 189,078 bytes, flash code remains 1,546,752 bytes, and
rodata measures 599,364 bytes within its existing allowance. The combined
compressed Web asset cap remains 120,700 bytes; 100 bytes of unused shell
allowance move to the runtime cap. Firmware task ownership, control timing,
OTA identity and partitions remain unchanged.
Urgent control-gate publication and the no-scale timer's stop fade add another
640 bytes of reviewed image/linked allowance, to 44,976 and 44,968 bytes.
The mobile full-screen Home shot card and the Brew by Weight master toggle
raise them once more by 2,048 bytes, to 47,024 and 47,016 bytes (measured
2,320,240 image bytes and 2,320,127 linked bytes). Both are browser-local
Web UI changes with no firmware task, control-timing, or memory-placement
impact; flash code, rodata, DIRAM, and external BSS remain within their
existing allowances. The combined compressed Web assets measure 122,530
bytes; the per-asset caps enforced by the Web contract tests are unchanged.
The record pages' move onto the owned WebSocket raises the image and linked
allowances by another 2,048 bytes, to 49,072 and 49,064 bytes (measured
2,321,920 image bytes and 2,321,799 linked bytes): the History and Stats
stream senders, the shared record UI/row projections, and the stream client
replace the REST read handlers. Flash code grows 32,700 bytes (inside its
32,768-byte allowance), rodata 14,844 and DIRAM 6,704 bytes (inside theirs);
external BSS is unchanged. The combined compressed Web assets measure
123,231 bytes; their per-asset caps are enforced by the Web contract tests.
The post-landed record-stream review raises the flash-code allowance by 512
bytes, to 33,280 (measured 1,548,180): the senders' no-change bookkeeping
now stores the epoch on the fingerprint-suppression path and on snapshot
sends, and the history fingerprint became component-wise over the raw
record bytes. Image, rodata, DIRAM, and external-BSS allowances are
unchanged.
The SoftAP onboarding feature (captive-portal DNS, probe redirect, SoftAP
admin bypass, live-apply save, /setup view) raises the flash-code allowance
by another 512 bytes, to 33,792, and the rodata allowance by 2,048 bytes,
to 18,432 (measured 1,548,556 flash-code and 605,644 rodata bytes on the
development Micra build). Code growth is the vendored AsyncUDP/DNSServer
reply path plus the bypass, probe-redirect, and live-apply handlers; rodata
is dominated by the embedded onboarding assets (the /setup partial, its
view module, and route wiring measured 129,368 combined compressed bytes in
the Web contract gate), which consume the roughly 1,940 rodata bytes the
record-stream change had left. The measured 2,321,200-byte image and
2,321,075 linked bytes stay inside their existing 49,072/49,064-byte
allowances, DIRAM grows 480 bytes for the DNSServer object and the stream
session flag (well inside its 8,192-byte allowance), and the reed/Silvia
development profile keeps passing with negative deltas against this
baseline. Firmware task ownership, control timing, OTA identity and
partitions remain unchanged. The /setup connecting-countdown assets push the measured
development rodata to 605,900 bytes (18,548 over baseline), so the rodata
allowance rises once more, to 19,456 bytes: the roughly 900 remaining bytes
deliberately absorb the documented version/asset-tag padding wobble so
routine commits do not trip the gate. Flash code measures 1,548,664 bytes
(228 bytes inside its allowance), the image 2,321,552 and linked 2,321,439
bytes, and DIRAM is unchanged.
The additional atomic priority flag retains the single HTTP workspace owner;
control only notifies Network and never waits for serialization. The stop fade
is browser animation state, with no firmware task or control-timing changes.
The runtime cap receives another 400 bytes from unused shell allowance, and
the combined compressed asset cap increases by 200 bytes to 120,900 bytes.
Flash-code, rodata, DIRAM and external-BSS limits remain unchanged, as do the
OTA identity and 3 MiB slot. The final Micra development image measures
2,318,576 bytes, with 2,318,459 linked bytes, 1,546,876 flash-code bytes and
599,780 rodata bytes. DIRAM remains 189,078 bytes and external BSS remains
757,144 bytes. The three-profile gate verifies these limits; combined assets
measure 120,888 compressed bytes within the 120,900-byte cap.
TLS certificate verification and the IANA 2026d catalog remain included.
The DIRAM baseline stays at 182,518 bytes with an 8,192-byte allowance;
the current build uses 189,078 bytes. External BSS remains under its separately
reviewed 800 KiB ceiling. The 3 MiB OTA slot remains the hard image limit,
with 827,152 bytes (about 26%) free in the measured build. Static measurements
do not qualify runtime heap or stack behavior.
The loop diagnostics and control-loop slimming series raises the image,
linked, flash-code, and rodata allowances once more, to 52,272, 52,264,
34,196, and 21,300 bytes. Two work streams share the growth: the loop
diagnostics commits (input sub-phase attribution, true own-CPU pairing with
the lock-free counter path) that landed above the last reviewed allowance,
and the status-publish slimming plus all-loop optimization series (status
sub-phase profiling with shot-store and control-status lock-wait telemetry,
the generation-guarded store gather, the per-dispatch stream fetch hoist,
and the Stats records cache with per-row curve fetches). The reference
development Micra build measures 2,325,968 image bytes, 2,325,847 linked
bytes, 1,549,232 flash-code bytes, 608,588 rodata bytes, DIRAM at 185,094
bytes (2,576 over baseline, well inside its allowance), and external BSS
at 762,248 of 819,200 bytes; the series also returns about 492 KB of
runtime PSRAM heap by dropping the whole-store curve copy from the network
workspace, which these ELF metrics do not capture. Each allowance carries
64 bytes of headroom over the measurement, following the established
padding-wobble convention. Firmware task ownership, control timing, OTA
identity and partitions remain unchanged.

The n16r8 PSRAM XIP profile moves flash instructions and read-only data to
PSRAM at startup and prefers PSRAM for the NVS page cache and key hash list,
with internal fallback. N8R4 retains its prior mapping and NVS allocation.
The n16r8 Micra development+JTAG build (`esp32-s3-relay-x1-speaker-reed` /
`la-marzocco-linea-micra`, ESP-IDF 6.1, validation at `79c4788-dirty`)
measured 2,123,936 image bytes, 2,123,811 linked bytes, 1,444,516 flash-code
bytes, 517,148 `.rodata` bytes, 177,438 DIRAM bytes (32,016 internal BSS), and
106,992 external-BSS bytes. The code and rodata require roughly 1.9 MiB of
PSRAM before mapping overhead. Linker figures do not measure runtime heap;
matched target memory, settings latency and loop-gap measurements remain
required before qualification. PSRAM access may slow NVS integer operations.

Both linker maps must also keep external BSS at or below 800 KiB (819,200 bytes) and retain
`localBuzzer` and `taskProfiler` in internal DRAM. Moving their enclosing
objects to PSRAM would move synchronization state accessed under spinlocks.
The same map check now requires the published control scalars, control gate and
their mutexes to stay internal, and the published curve payload to reside in
external BSS. Runtime session fingerprints remain part of the explicitly
external Network allocation.
The timestamped-curve Micra development profile measured 756,272 external-BSS bytes,
183,510 DIRAM bytes and a 2,188,640-byte image with the task-only pending finalizer
in PSRAM. This ceiling detects
static-placement regressions; it is not the physical PSRAM limit or a
runtime-heap measurement. The earlier 96→104 KiB increase covered the V3
half-second shot-curve store, and the 112→240 KiB increase covers the
96→512-event diagnostic log ring, whose static PSRAM ring and serial dump
snapshot grew by about 123 KiB. The current 240→800 KiB increase covers the
498,420-byte accepted-observation cache, its bounded disk workspaces, the
1201-observation sampler and task-owned finalization/serialization staging.
The immutable persistence image is separately allocated in external heap.

## Home shot stream target measurements

The 2026-10-05 comparison used the same ESP32-S3 N16R8, speaker/Micra
development pair, ESP-IDF 6.1, retained settings/history, disconnected scale,
disabled scale recording and existing cloud/webhook connections. Baseline
`0501da90` and corrected stream firmware `93dc21a4` were USB-installed and
sampled with the same procedure through 64 seconds after restart. These are
measured reference workloads, not new limits or full hardware qualification.

| Measurement, bytes unless stated | Baseline | Home stream | Difference |
| --- | ---: | ---: | ---: |
| Settled internal free heap | 80,971 | 80,063 | -908 |
| Lifetime minimum internal heap | 31,232 | 30,240 | -992 |
| Settled largest internal block | 40,960 | 40,960 | 0 |
| Reported PSRAM heap capacity | 5,467,008 | 5,462,016 | -4,992 |
| Settled PSRAM free heap | 4,187,424 | 4,182,512 | -4,912 |
| Lifetime minimum PSRAM heap | 4,132,076 | 4,135,112 | +3,036 |
| Settled largest PSRAM block | 4,128,768 | 4,128,768 | 0 |
| Linked DIRAM | 187,158 | 187,494 | +336 |
| External BSS | 756,976 | 757,144 | +168 |
| Firmware image | 2,292,288 | 2,310,512 | +18,224 |

Reported PSRAM capacity changed with the image; allocated PSRAM at the settled
comparison point was 80 bytes lower. Free-heap differences alone therefore do
not describe dynamic allocation growth. Separate boots measured internal minima
of 31,232–37,088 bytes for the baseline and 30,184–36,196 bytes for the corrected
firmware. Startup traces placed the transient dips around existing outbound
connections and the 52 KiB startup reservation; compare matched workloads rather
than attributing a lifetime minimum to the Home stream alone.

Two 100-reconnection runs recovered their initial internal free/minimum/largest
figures. A bound/overlapping connection temporarily reduced the largest internal
block by 2 KiB; it recovered after cleanup. Idle stream CPU samples were
0.35–0.46%, versus 0.25–0.30% settled without a stream. A 200-request resync burst
produced 25 snapshots over the burst and drain interval. A stalled reader closed
and a fresh stream recovered; concurrent Home/Stats/History/OTA-status requests
completed, with a worst observed response of 744 ms under three HTTP workers.
No additional external-allocation fallback or HCI drops were observed. A full
2,310,512-byte same-image OTA transfer also completed with the stream occupied;
the stream recovered after socket recycling during upload and after reboot.
The new boot's image digest matched and automatic confirmation succeeded.

The target's 396-point canonical snapshot was 4,730 bytes and matched Stats
weights, timestamps and breaks exactly. An offline maximum-width 1201-point
curve with every possible break and all event markers serialized to 20,703
bytes inside the existing 22,016-byte curve workspace. Active scale/drip timing,
maximum-curve target sends, HTTP-task stack margin and server-stop overlap remain
manual qualification requirements. OTA power-cut, safety-abort and rollback
cases also remain pending; the successful full transfer does not qualify them.
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

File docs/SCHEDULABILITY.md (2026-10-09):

# Scheduling qualification

The authoritative task contract is `OpenBrewByWeightScheduling.h`. It fixes core,
priority, nominal period, service deadline and Task Watchdog participation for
every application task. A task without a periodic deadline is event-driven or
diagnostic and must never execute on a safety path.

## Application task contract

`max block` is the largest explicit API timeout reachable in one activation;
it is not a measured WCET. `unbounded` is intentional for the isolated serial
sink: USB backpressure may block it forever, so it is neither watchdog
subscribed nor part of control. Stack values are configured bytes in ESP-IDF.

| Task | Activation / period | Deadline | Execution budget | Priority | Max block | Stack | Core | TWDT |
|---|---:|---:|---:|---:|---:|---:|---:|---:|
| control | periodic / 1 ms active | 10 ms | 9000 us | idle+1 | 50 ms maintenance flash take | 8192 | 1 | 5 s |
| scale_worker | notification / 1 ms connecting or unlinked queued command, 10 ms linked/idle | 10 ms | 9000 us | idle+1 | 3000 ms GATT step | 6656 | 1 | 5 s |
| settings_persist | event-driven | 1000 ms service | n/a | idle | 3000 ms lock acquisition; one flash primitive/step | 4096 | 0 | 5 s |
| health | periodic / 100 ms | diagnostic | n/a | idle | none | 4096 | 0 | no |
| network_manager | periodic / 50 ms | 250 ms | 200000 us | idle+1 | 2500 ms lifecycle/cancel | 10240 | 0 | 5 s |
| mdns | event-driven (action queue) | n/a | n/a | 1 | freed once in network stop | 4096 | 0 | no |
| httpd | framework event | n/a | n/a | idle+1 | 30000 ms OTA receive budget | 11264 | 0 | no |
| webhook | event-driven | n/a | n/a | idle | 1800 ms HTTP | 4608 | 0 | no |
| micra_cloud | event-driven | n/a | n/a | idle | 10000 ms per HTTPS request | 8192 | 0 | no |
| websocket_task | SDK transport events | n/a | n/a | 1 | 10000 ms network timeout | 6144 | 0 | no |
| serial_log | event-driven | n/a | n/a | idle | unbounded USB sink | 3072 | 0 | no |

The control task keeps safety, machine sampling and actuation, brew guards,
scale-event drains, maintenance cancellation, Web commands, power transitions,
alerts, the compact remote-control gate, and watchdog service on every
activation. Administrative polling for the serial CLI, persistence completion,
diagnostic weight-stream state, the full Web status snapshot, and the scale
status LED runs at boot and then every 10 ms. This cadence does not change the
1 ms active control period or its 10 ms service deadline.

The 10 ms service deadline does not apply while `scale_worker` is executing an
explicit connection/discovery operation whose bounded step is listed above;
those paths are separately bounded by the 5 s TWDT. HIL qualification must
report active-link and connect/discovery distributions separately.

The optional Micra cloud service owns a low-priority core-0 worker so HTTPS and
signature work never enters the scale or control task bodies. HTTPS uses the
ESP-IDF asynchronous client contract: incomplete progress yields for one tick,
rechecks the network/scale/shot gates, and retains one absolute 10-second
operation deadline. The network manager publishes the current gate and wakes
the cloud worker in the same activation. Only the cloud worker accesses or
destroys its HTTP/TLS client; cancellation is checked before and after each
asynchronous progress call, so teardown cannot race an in-flight TLS read.
The API-mode observer is due nominally every 30 seconds, and its four-attempt cycle
waits 3, 6, then 9
seconds. After exhaustion API observation resumes its 30-second cadence;
WebSocket reconnection and command retries use a 60-second cooldown.
WebSocket failure backoff starts after cleanup or the failed setup operation
returns, so transport delays do not consume the following retry interval.
WebSocket selection suppresses regular polling. Each admitted subscription
queues one initial dashboard cycle with the same bounded retries, coalescing
compatible queued observations. Explicit offline-to-online recovery can queue
one resynchronization read. The SDK receiver runs independently on core 0,
priority 1, with a 6144-byte internal stack and fixed 1024-byte I/O buffers.
CONNECT/SUBSCRIBE and incomplete-frame progress each have a 10-second deadline.
Payload processing decodes each header once, accumulates the body in linear
time, admits at most 32 complete frames per feed and yields after publication.
The facade records validated-frame→publication and pause→actual stop latency.
The publication metric covers JSON decoding and facade publication; transport,
fragment assembly and STOMP decoding require separate callback timing in target
traces. Target qualification must establish those bounds under HTTP load.
An established socket follows owner stop; DNS/connect already in flight may
finish before SDK stop completes. BLE never waits for that completion.

Backflush processing drains at most eight transitions per control turn. A
published supervision loss opens on the next turn; silent transport loss is
detected no later than the 30-second pong/connection liveness budget plus
control scheduling latency. Pongs prove transport reachability, not machine
state freshness. The independent relay deadline remains 60 seconds until
qualified promotion, then 180 seconds from the original close, regardless of
worker or cloud progress. Measure these bounds on target under concurrent load.

AP, STA-loss, unsynchronized clock, scale acquisition/setup/quiet, and shot
activity gate every API purpose, including authentication and retries, without
consuming attempts while awaiting admission. Every gate must clear before work
resumes. These are admission intervals, not a guaranteed cloud
detection latency; an individual TLS/crypto progress call still requires target
deadline qualification.
Shot→rinse classification clears the shot gate immediately. WSS does not
participate in scale acquisition/setup/quiet admission.
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

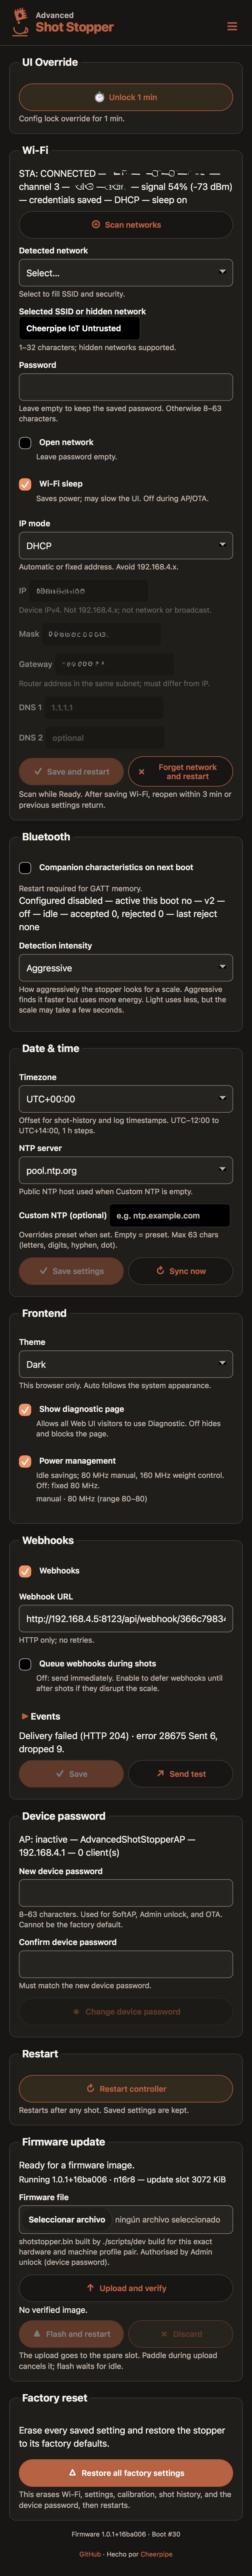
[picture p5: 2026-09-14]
docs/images/screenshot-admin-dark.jpeg

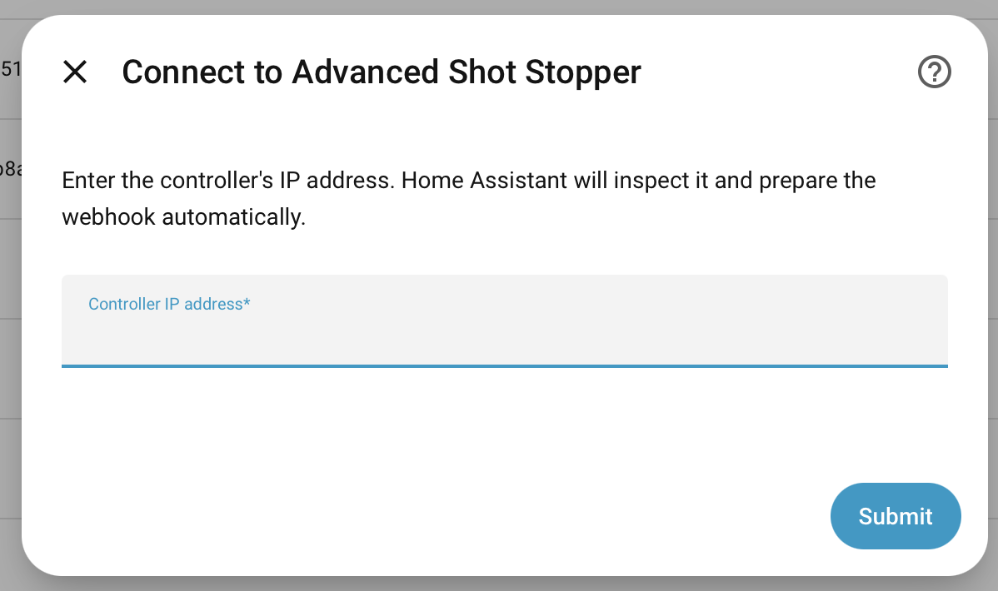
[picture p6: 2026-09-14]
docs/images/home_assistant_configuration.png

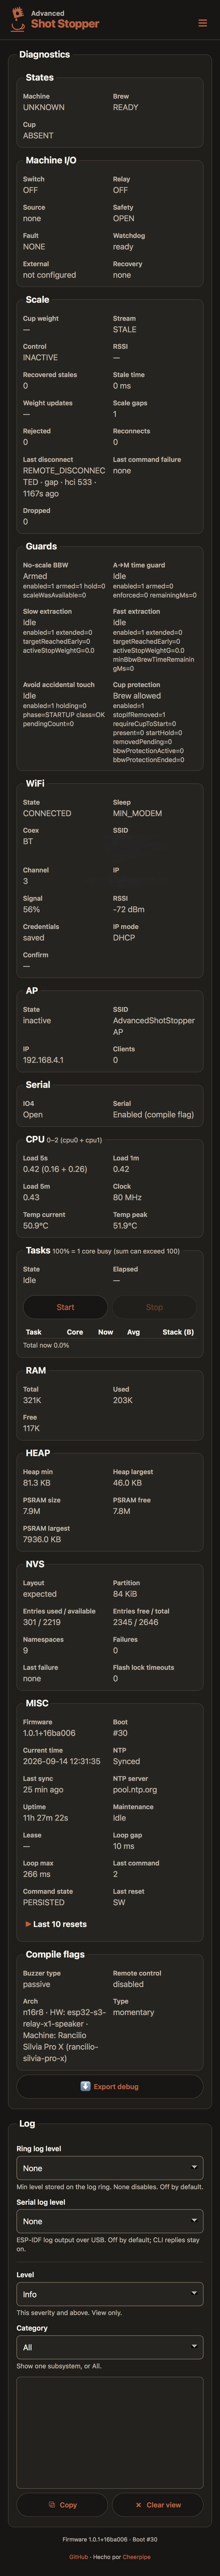
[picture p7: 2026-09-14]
docs/images/screenshot-diagnostic-dark.jpeg

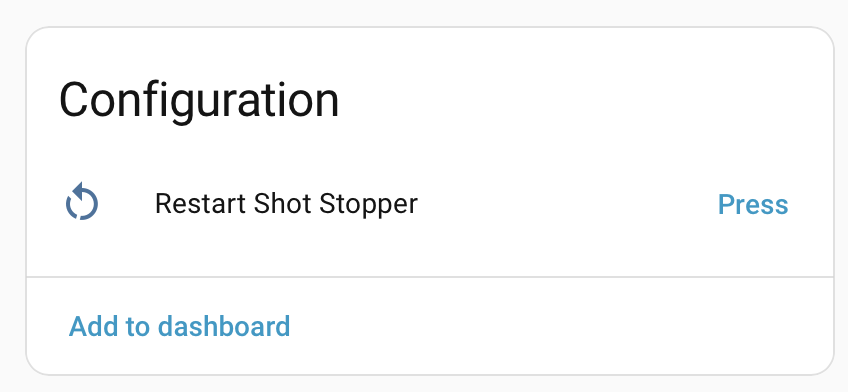
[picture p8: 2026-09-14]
docs/images/home_assistants_actions.png

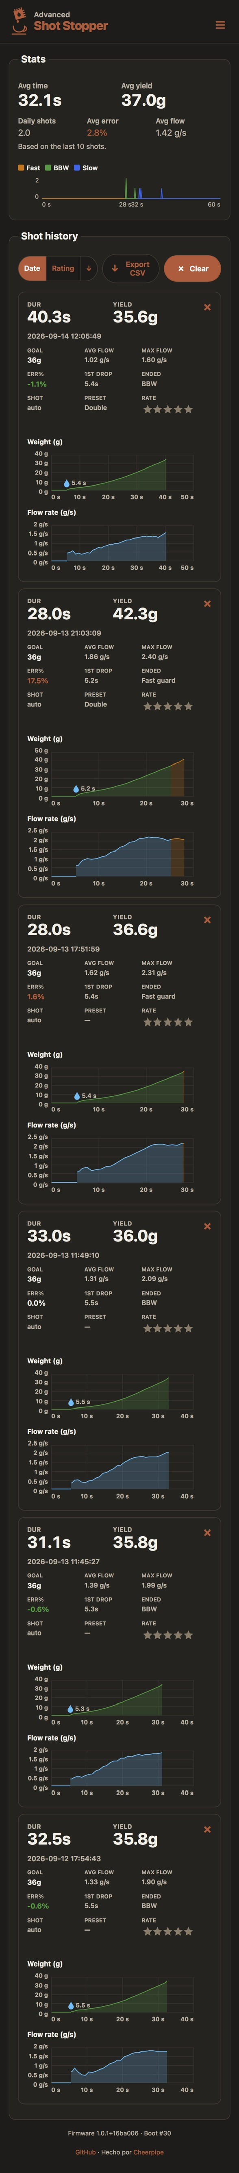
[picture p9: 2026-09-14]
docs/images/screenshot-stats-dark.jpeg

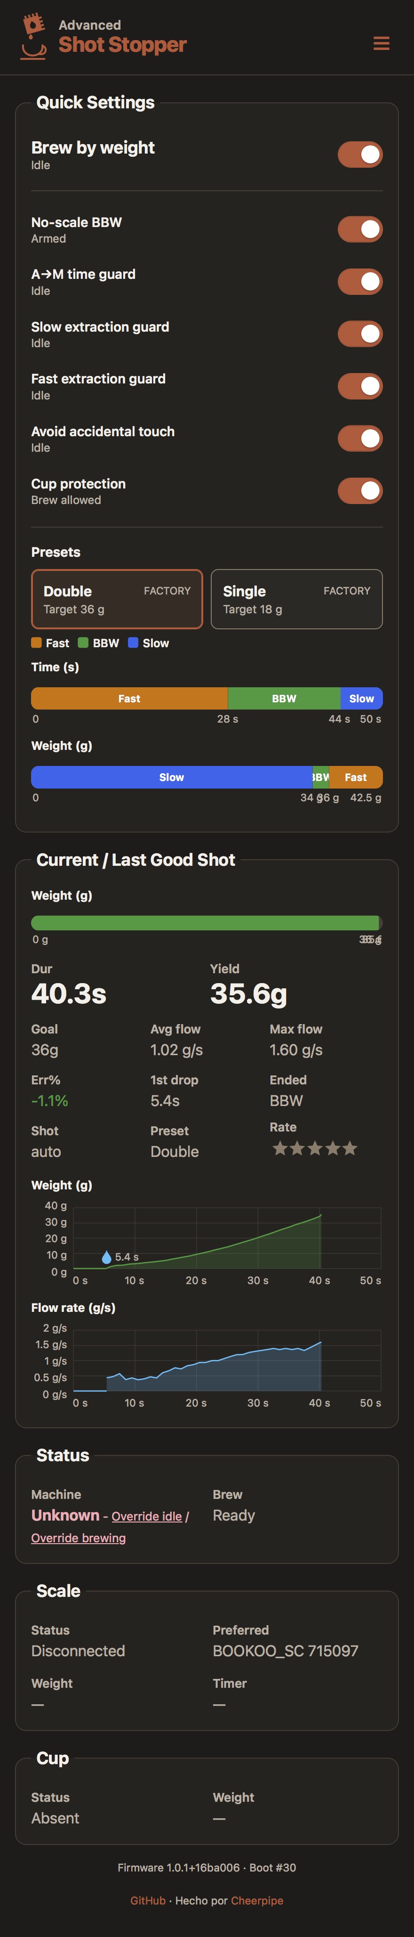
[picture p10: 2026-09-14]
docs/images/screenshot-home-dark.jpeg

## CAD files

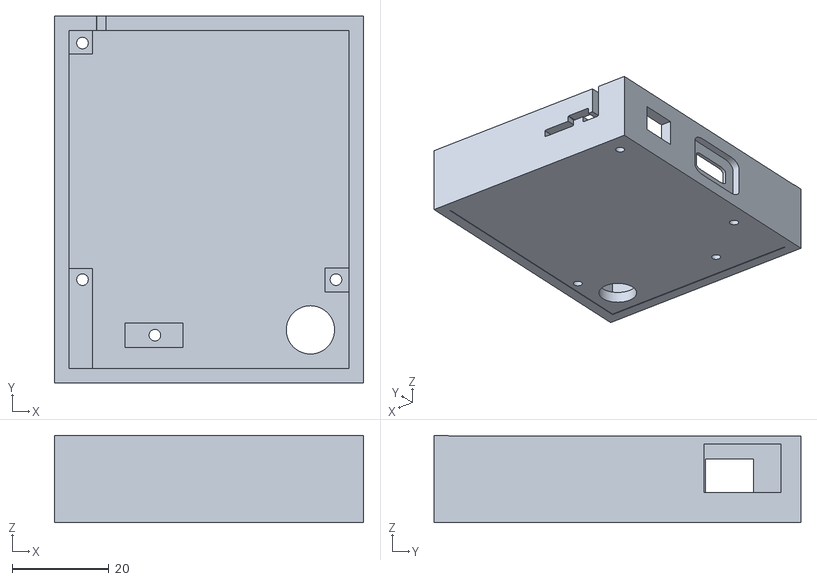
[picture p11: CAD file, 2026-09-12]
stl/AdvancedShotStopper-Box-thick.stl
64.0 x 76.0 x 18.1

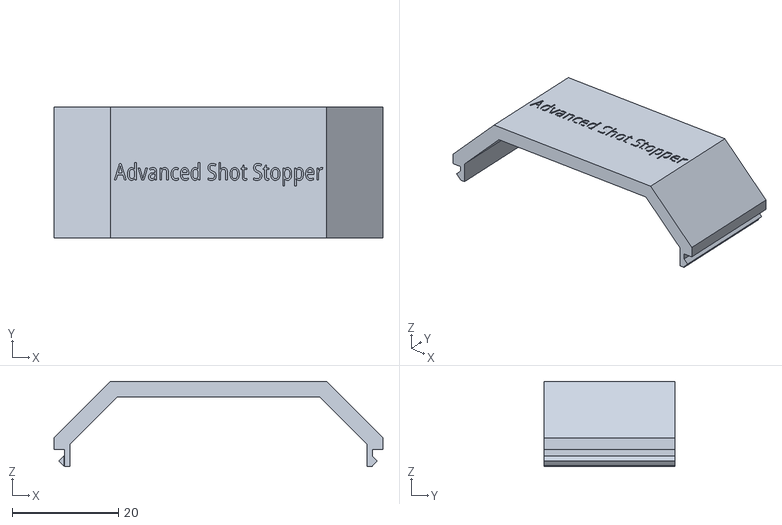
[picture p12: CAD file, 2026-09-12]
stl/AdvancedShotStopper-Cover-thick.stl
62.0 x 24.7 x 16.1

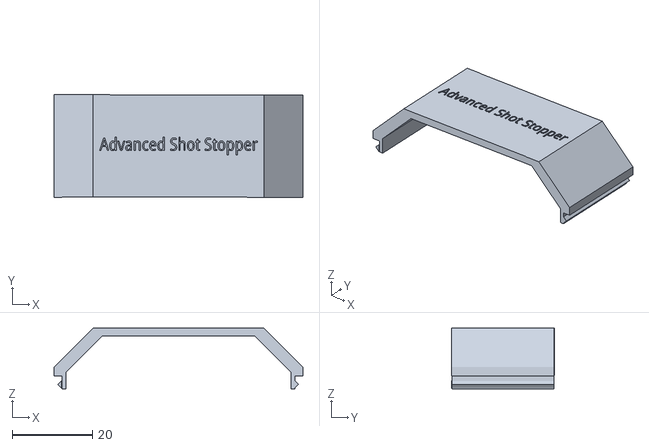
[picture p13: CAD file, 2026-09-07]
stl/AdvancedShotStopper-Cover.stl
62.0 x 25.7 x 15.1

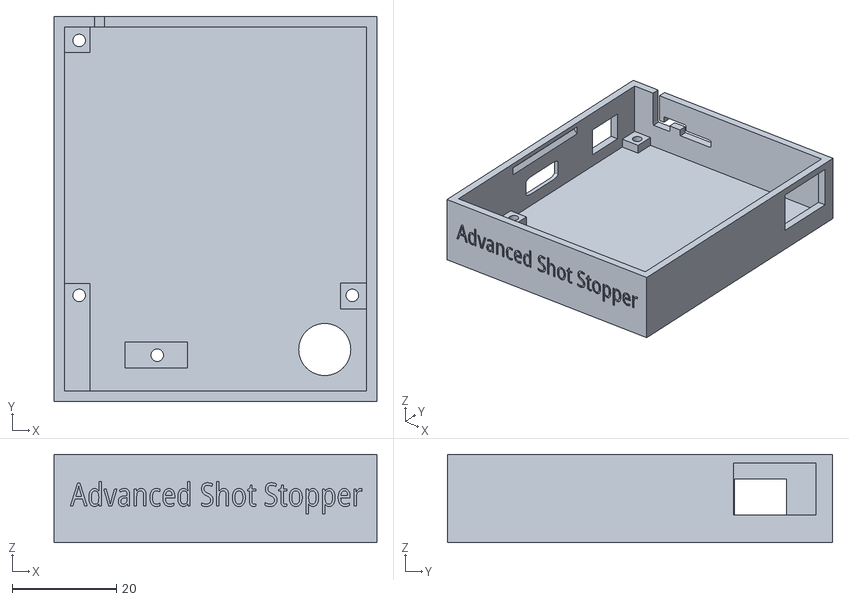
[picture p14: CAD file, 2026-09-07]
stl/AdvancedShotStopper-Box.stl
62.0 x 74.0 x 17.0

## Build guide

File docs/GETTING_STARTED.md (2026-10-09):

# First setup and daily use

Use this guide after firmware installation and the applicable
[bench checks](MANUAL_TEST_PLAN.md). For equipment and wiring prerequisites,
start with [Hardware](HARDWARE.md).

## Connect for the first time

1. Keep the physical activator OFF (release a momentary button) and power the
   controller. Turn on the scale with no other app connected to it.
2. On your phone or computer, join the controller's
   [setup network](settings/ap.md#first-connection). The name is
   **`OpenBrewByWeightAP-`** plus eight characters unique to this controller
   (USB `AP_STATUS` shows the exact name) and the password is the device
   password (**`ineedacoffee`** from the factory). Stay joined even if your
   phone reports "no internet".
3. The setup page opens on its own within a few seconds — choose your home
   network, type its password, and select **Connect**. If the page does not
   open by itself, browse to **`http://192.168.4.1/setup`**. The controller
   joins your network without restarting: the page shows the addresses to use
   from now on (`<name>.local` and the controller's new address) and keeps
   the setup network open for about a minute so you can note them — select
   **Done** when you have them. No other password is asked during this
   flow.
4. Rejoin your home network on the phone/computer and open the controller at
   the address the setup page showed. On most home networks
   `openbrewbyweight.local` answers (a renamed controller answers at
   `<name>.local`). If that name does not open, find the controller's IP
   address in the router's connected-device list or via
   [USB NET_STATUS](SERIAL_CLI.md).
5. If the Web UI shows **Reload**, select it to claim this browser session,
   then open **Admin** and unlock it with the device password.
6. Change the factory device password in **Admin → Device password**. It is
   shared by Admin and the setup network. If you later use the setup network
   again, join it with the new password.

A wrong password in the setup page can be corrected right there — the
controller keeps its setup network alive and keeps trying for about three
minutes before it falls back to the previous settings.

You can also operate locally over the setup network while your client remains
associated. The [AP guide](settings/ap.md) explains its idle shutdown and
recovery.

## Web access

**Claim / Reload** gives one browser control of Home and Settings. Another client
can take the claim, and 15 minutes without using a control locks the page and
stops live updates. Scrolling does not keep it active; use Reload to resume.
The page stays active while a shot is running, so it never locks mid-shot.

Home updates automatically when its information changes. In **Equipment → Scale**,
weight and timer follow the connected scale even outside a shot. Disconnecting
the scale clears those readings. **Equipment → Machine** follows the machine and
brew states; on a Linea Micra, it also shows power and **Machine cleaning
(backflush)**, with the same cleaning state shown in Diagnostics. Cleaning status
requires the Micra WebSocket connection and state observation to be enabled.

On a phone or tablet, the shot card has a small expand button in its top-right
corner. Tap it to spread the card across the whole screen, always in landscape,
with the same live readings and proportions as the Home card. Tap the × in the
corner, or use your device's back gesture, to leave the full-screen view; it
closes like a panel and does not leave Home.

The header shows the controller's home-network Wi-Fi signal and its Bluetooth
link to the scale. More lit arcs or bars mean a stronger signal; amber means
weak reception. Tap Wi-Fi to see the connected network name and signal level;
tap Bluetooth to see the connected scale and its signal level. These indicators
update when reception moves between weak, medium, and strong; the popups show
the level rather than a fluctuating dBm reading. The scale uses
your friendly name when set; otherwise it shows the scale's model name when
recognized, or the name reported over Bluetooth. Tap the same
icon again, tap outside the popup, or press Escape to close it. A crossed-out
Bluetooth symbol means the scale is disconnected.
Dim icons without a cross
mean a reading is not available yet, or the page cannot refresh it. The Wi-Fi
icon describes the home-network connection, even when you open the page through
the controller's own access point.

Use the rounded navigation bar to open Home, Stats, History, Settings,
Diagnostics or Admin. When there is enough room, it sits beneath the logo,
matches the content width and shows an icon beside each section name. As the
window narrows, the icons disappear first. When the names no longer fit, the
bar moves to the bottom and shows icons only. The current page is highlighted.
With navigation in the header, the gray area is visible at the top of the page.
As you scroll, the logo and connection indicators move out of view while the
menu floats over the content near the top of the screen. Return to the top to
restore the complete header.
Diagnostics appears only when **Show diagnostic page** is enabled in
**Admin → Frontend**; hiding it gives the other buttons more room.
The phone header shrinks gradually as you scroll, keeping the logo and connection
icons visible. Return to the top to restore its full size.

**While a page loads**: Home, Settings, Stats, History, Diagnostics, and Admin
show a loading view with the Open Brew by Weight mark, a moving wave, and
**Loading…**. Opening or refreshing the URL covers the whole screen. When you
switch pages using the menu or the browser's Back and Forward buttons, it covers
the content below the header, leaving navigation available.
It also appears when you return to a page you have already visited. Controls
appear directly in their current positions, without animating during loading or
the fade. As soon as the page's data is ready, the loading view fades away in a
quarter of a second.
Control animations work normally once the page is visible. Stats, History, and
Settings use this single loading view rather than separate loading animations
inside their sections.
On first opening a page, its content and fresh data load together. Returning to
a page reuses its content and controls with current data. Stats and
History request their current status and records together, and the loading view
waits for both before fading.
If loading fails, the page shows an error. If this browser loses its claim, the
loading view hands over to **Reload**.

**Add to home screen** installs the page like an app. On iPhone or iPad, open
the controller page in Safari, tap **Share**, then **Add to Home Screen**; from
then on it opens full screen with the Open Brew by Weight icon — the brand mark
on the brand colour, edge to edge, so it fills its place on the home screen
without a white frame around it. On Android, open the controller page in Chrome,
tap the **⋮ menu**, and choose **Add to Home screen**. Because
the controller is reached directly at its local address, browsers do not offer
an automatic install prompt — the menu option above is the installation. The
icon is taken from the page when you add it, so an icon added before a firmware
update keeps the artwork it was installed with: remove it and add the page again
to pick up the current one.

**Out of reach**: when the page opens but the controller cannot be reached —
for example while you are away from home — it shows the Open Brew by Weight logo with
an out-of-reach message and a **Reload** button instead of a raw error. The same
message appears if the connection drops while the page is open; in that case
the page resumes on its own once the controller answers. When the page opens
straight into the message, check that the phone or computer is connected to the
same network as the controller, then press **Reload**. Right after a firmware
update the message can appear while the controller restarts; wait a moment and
press **Reload**. If the browser has no saved copy of the page yet, it shows
its own cannot-connect page instead.

**Admin unlock** is an additional password check for privileged actions.
The **Firmware** section in Admin holds a master switch that can turn every
brewing feature off and leave the controller as a transparent pass-through;
see [firmware mode](settings/firmware-mode.md).
It stays renewed while Admin is open, or expires 15 minutes after the last
privileged action. **Lock** closes it immediately without releasing the browser
claim. Most configuration changes require an idle machine.

Open any Web UI page to set up the time zone from this phone or computer when
the controller is idle; unlocking Admin is not required. Setup continues until
the zone has been saved successfully. In **Admin → Date and time**, automatic
mode follows the device using the UI. Turn it off to choose a zone manually,
check the preview, and save your settings. See
[Time zone and NTP](settings/wifi.md#parameters-and-behavior).

Save buttons in **Settings** and **Admin** stay dimmed until you change one of
their values. When you save, the small icon on the button turns into a spinning
ring while the controller applies the change. A successful save dims the button
again; if saving fails, the button remains available so you can retry and the
red message bar explains the error. Every save button has a smaller revert
button beside it with a circular arrow. It lights up together with the save
button, and tapping it asks for confirmation and then puts the section's fields
back to their last saved values, so you can walk away from edits you did not
mean to keep.

Remote start/rinse are disabled in default firmware. Admin unlock does not
enable them. Remote Stop is privileged; physical controls remain available
according to the selected [paddle](settings/paddle.md) or
[momentary](settings/momentary.md) behavior.

## Connect the scale and choose a recipe

1. Check Home for a connected scale and a fresh weight reading. A Bluetooth
   connection alone is not sufficient for automatic weight control.
2. On a new controller, **Prefer selected → First detected** adopts the first
   compatible scale that connects successfully and then prefers it. To replace
   it or use several scales, follow [Scales](settings/scales.md).
3. In **Settings → Brew**, load **Double** or **Single**. For your own recipe,
   duplicate a preset, change the target and guards, and save.
   [Presets](features/presets.md) lists the factory values.
4. For a latch/paddle installation, start with **Natural**, the default mode.
   Momentary builds show **Switch** instead; use their
   [button and sensor settings](settings/momentary.md).
5. Leave Quick rinse off until you have tried its
   [gesture deliberately](settings/quick-rinse.md).

## First shot

With a usable scale, BBW enabled, the factory Double preset, Natural paddle
mode, and Quick rinse off:

1. Place your cup on the scale.
2. Move the paddle ON. The controller tares the scale and starts the timer.
3. Leave it ON while brewing. The nominal goal is 36 g; the controller
   compensates for dripping, and Fast/Slow guards may change the endpoint.
   To finish early in Natural mode, move the paddle OFF.
4. After automatic stop, return the paddle to OFF before starting again.
5. Leave the cup on the scale through the drip delay (default 3 s). The final
   weight then updates Last Shot and, if eligible, history.

While brewing, a card at the top of Home follows the shot live — weight
against the goal, elapsed time, flow, and the first drop. After the stop it
keeps the result and shows the stop mode (BBW, Fast/Slow guard, A→M, manual).
The link at the bottom-right of the card opens the shot history on the Stats
page. The card's elapsed time advances in whole seconds while brewing; when
the shot ends, it shows the final duration with one decimal place.

On a **momentary** machine, press and release to start; another valid press
requests stop. Automatic stop uses a pulse, not a continuously open contact.
Without reed feedback, the running state is inferred and can be wrong.
Read [Stopping and time limits](settings/momentary.md#stopping-and-time-limits)
before relying on automatic operation.

## Common next steps

| Situation | What to do |
| --- | --- |
| Cup placed after starting | Place it within the [retare window](features/tare-retare.md); later placement is not automatically corrected. |
| Shot ends above or below target | Read the stop detail in [history](features/shot-history.md), then check Fast/Slow and learned offset. |
| Scale unavailable before start | Follow [No-scale BBW](settings/no-scale-bbw.md); the default first attempt warns and blocks. |
| Scale disconnects during brewing | Weight stop pauses; [A→M](features/auto-to-manual.md) may request a timed stop while reconnection continues. |
| Need a timer-only session | Turn BBW off in Home Quick Settings. It does not rewrite the saved recipe. |
| Cannot save a setting | Finish the cycle, return the activator to idle, reclaim the UI if necessary, and check Admin unlock for privileged settings. |
| Cannot reach the controller | Use [network troubleshooting](FAQ.md#network-and-access) before considering a reset. |

Next: [settings index](README.md#settings) · [troubleshooting](FAQ.md) ·
[updates](features/ota.md).

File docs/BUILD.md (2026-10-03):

# Build, test, and install

Supported firmware uses ESP-IDF **6.1.0** (release tag **v6.1**),
Arduino-ESP32 **3.3.12** as an IDF component, and native NimBLE.
The bundled EspressoScaleBLE library is not installed through Library Manager.

Production defaults compile DFS (`CONFIG_PM_ENABLE`) and S3 controller modem
sleep with the main crystal. The runtime [Power management](settings/power-management.md)
setting defaults off. The build wrapper recreates cached configurations missing
this support; automatic light sleep remains disabled.

This walkthrough covers macOS and Debian/Ubuntu Linux. Native Windows build
and hardware-installation steps are not qualified here; the Windows notes in
[Static analysis](STATIC_ANALYSIS.md#4-windows-prerequisites-native-no-wsl)
cover tool preparation only.

Read [Hardware](HARDWARE.md) before connecting equipment. Building and host tests
do not need a connected controller. Flash/OTA sections explicitly affect it.

## 1. Clone the repository

```sh
git clone https://github.com/Cheerpipe/Advanced-Shot-Stopper.git AcaiaArduinoBLE
cd AcaiaArduinoBLE
```

Use your fork's URL when contributing. Commands below run from this repository
unless a block explicitly changes directories.

## 2. Install host prerequisites

macOS, with Homebrew installed:

```sh
xcode-select --install   # only if Command Line Tools are missing
brew install git python cmake ninja cjson node cppcheck
```

Ubuntu 24.04 (the reference host version):

```sh
sudo apt-get update
sudo apt-get install git python3 python3-pip python3-venv cmake ninja-build \
  wget flex bison gperf ccache libffi-dev libssl-dev dfu-util libusb-1.0-0 \
  g++ libcjson-dev curl libdigest-sha-perl
```

Node.js and Cppcheck come from the same package managers as the rest of the
host tools; the project deliberately keeps no version pin for either, so a
current release installed on the machine is what every script uses. Check
`python3 --version`, `cmake --version`,
`ninja --version`, and `c++ --version`; CMake must be **3.25 or newer** to read
the repository's version-6 presets. If a distribution package is older, upgrade
that tool before continuing. Debian and other Ubuntu releases can work, but
their package versions must pass these checks; Ubuntu 24.04 matches the
reference host.

| Dependency | Local version contract | Source of truth |
| --- | --- | --- |
| Node.js | No pin; any current release resolved from `PATH` | [`./scripts/dev doctor`](../scripts/dev) |
| Web UI packages | Exact direct and resolved versions via `npm ci` | [`package.json`](../package.json), [`package-lock.json`](../package-lock.json) |
| ESP-IDF | Exactly 6.1.0 (tag v6.1) | This guide and the build scripts |
| IDF components | Locked graph, including mDNS 1.13.1 and ESP WebSocket client 1.8.0 | [`idf/dependencies.lock`](../idf/dependencies.lock) |
| Cppcheck | No pin; any current release resolved from `PATH` | [`./scripts/dev doctor`](../scripts/dev) |
| Host CMake | 3.25 or newer | [`CMakePresets.json`](../CMakePresets.json) schema 6 |
| Home Assistant tests (optional) | Python 3.14.2 or newer; dependencies locked with uv | [`pyproject.toml`](../integrations/OpenBrewByWeight/pyproject.toml), [`uv.lock`](../integrations/OpenBrewByWeight/uv.lock) |
| Home Assistant service (optional) | No running service for tests; integration test dependency is 2026.9.x | [Integration project](../integrations/OpenBrewByWeight/pyproject.toml) |

Git, Node.js, Cppcheck, the host compiler, Ninja, cJSON and the system Python
have no separate
project pin; use versions compatible with the requirements above and verify
them with the tests below. ESP-IDF manages its own Python environment. The
[Home Assistant integration](../integrations/OpenBrewByWeight/README.md) has a
separate Python and `uv.lock` contract; it is not needed for firmware builds.

Install the pinned Web UI dependencies from the repository root:

```sh
npm ci
```

This is an explicit setup step. Test commands never install dependencies.

## 3. Install ESP-IDF

Prefer the [ESP-IDF Installation Manager (EIM)](https://docs.espressif.com/projects/idf-im-ui/en/latest/):
install ESP-IDF **6.1.0** (tag **v6.1**), open a fresh shell, and source
the activation script printed by EIM (or use **Open IDF Terminal** in its GUI).
For example, use the actual filename EIM created:

```sh
source "$HOME/.espressif/tools/activate_idf_v6.1.sh"
idf.py --version
```

The project scripts reuse an active environment only when `IDF_PATH`, its
`IDF_PYTHON_ENV_PATH/bin/python`, `idf.py`, and the reported 6.1.0 version all
agree. A stale or mismatched active environment is discarded before fallback.

When the legacy SDK's own activation script points at a Python environment
that no longer exists on the machine (for example after a macOS or Python
upgrade), the scripts pick up an installed environment for the same 6.1
release from `~/.espressif/python_env` automatically, preferring the newest
one. If none matches, the activation error names the missing directory so you
can run the install script for it.

The supported legacy fallback is a separate SDK clone. This subshell returns
you to the repository when installation finishes:

```sh
(
  mkdir -p "$HOME/esp"
  cd "$HOME/esp"
  git clone -b v6.1 --recursive https://github.com/espressif/esp-idf.git esp-idf-v6.1
  cd esp-idf-v6.1
  ./install.sh esp32s3
)
. "$HOME/esp/esp-idf-v6.1/export.sh"
idf.py --version
```

If that SDK directory already exists, verify its version instead of cloning
over it. For an inactive legacy SDK elsewhere, export `IDF_PATH`; the scripts
source its `export.sh`. Otherwise they discover `$HOME/esp/esp-idf-v6.1`.
Every path rejects versions other than 6.1.0.

`idf/main/idf_component.yml` and `idf/dependencies.lock` define the component
graph, including mDNS 1.13.1 and ESP WebSocket client 1.8.0. The WebSocket
component supplies selectable Micra WebSocket observation; authentication and
commands remain HTTP. The build fails if dependency resolution changes
the lockfile; review and commit such updates separately. First firmware builds
may need network access to resolve SDK components; prepare these dependencies
before attempting an offline validation run. Host tests and firmware compilation
need no running Home Assistant service or connected controller.

### Upgrade dependencies deliberately

Run `npm ci` and `uv sync --locked` for ordinary setup; neither updates its
lockfile. To upgrade a Web UI package, choose its version with
`npm install --save-dev --save-exact <package>@<version>` and review both npm
files. To upgrade a Home Assistant test dependency, update `uv.lock` explicitly
with `uv lock --upgrade-package <package>` and review the resolved graph.
An ESP-IDF upgrade must change the local version guard and the generated
component lock together; regenerate the lock with the intended
SDK version, then run the full build gate. Do not hand-edit lockfiles.

## 4. Validate before installation

`./scripts/dev` is the canonical entry point:

```sh
./scripts/dev test normal
./scripts/dev test web
```

A passing host run ends with CTest's success summary; the command prints the
full-log/JSON summary location in `artifacts/runs/`. Missing tools, cJSON, or
Node dependencies are failures, not skipped tests.

For changed code, run `./scripts/dev classify` and the complete gate from
[VALIDATION.md](../VALIDATION.md), including sanitizers/builds where required.
Host tests cannot verify wiring, radio timing, or physical stop behavior.
R2/R3 validation compiles every supported profile with the `--development`
profile, including the Linea Micra pair, so a passing gate leaves the
conservative local image ready in its normal `build-idf/<hardware>--<machine>/`
directory.

### Optional: Home Assistant integration tests

This is a separate Python environment; it is not required for firmware or Web
UI checks. Install a current uv with its
[installer](https://docs.astral.sh/uv/getting-started/installation/)
or a version manager, then run from the integration directory:

```sh
cd integrations/OpenBrewByWeight
uv --version               # any current uv
uv python install 3.14
uv sync --locked --group test
uv run --no-sync python --version    # Python 3.14.x
uv run --no-sync pytest
uv run --no-sync ruff check .
uv run --no-sync mypy
cd ../..
```

The integration's `uv.lock` fixes package resolution, `--locked` rejects a
stale lockfile, and `--no-sync` prevents test commands from changing the
environment. These
checks do not require a running Home Assistant instance or controller.

## 5. Build

Prefer named hardware and machine profiles. A hardware profile selects the
assembled board, memory layout, GPIO wiring, relay polarity, and installed
peripherals; a machine profile selects its control topology and factory
defaults. See [Hardware and machine build profiles](BUILD_PROFILES.md) for the
complete contracts and compatibility rules. The reference combination, used in
the examples throughout this guide, is:

```sh
./scripts/dev build \
  --hardware esp32-s3-relay-x1-speaker \
  --machine la-marzocco-linea-micra
```

Both options are required together. The X1 profile always resolves to
**n16r8** (16 MB flash / 8 MB OPI PSRAM). It writes to
`build-idf/esp32-s3-relay-x1-speaker--<machine>/` and also creates a `.bin`
whose filename contains that complete variant.

Every successful `build` also preserves the matching `shotstopper.elf` and
`shotstopper.bin` under
`artifacts/firmware/<hardware>--<machine>/<ELF SHA>/`, alongside
`identity.json`. The SHA is the one printed in an ESP32 panic log; its prefix
can locate the matching archive. These Git-ignored copies are created without
flashing and are retained by `./scripts/dev clean`. A later build cannot replace
an archive whose SHA already exists with different files.

Explicit `--flags` are applied after the JSON values. Supported profile values
are reflected in the resolved manifest; additive compiler flags keep working.
The resolver rejects unsafe or contradictory overrides, including GPIO
collisions, a machine that requires absent reed hardware, a normally-closed
relay profile, or a different `--arch`. Development mode remains CLI-only and
must never be added to a profile.

Machine defaults seed a new installation and factory reset. Valid persisted
settings survive ordinary boot and OTA. The current settings blob is schema 2;
same-layout schema-1 settings upgrade without losing saved values. The shot store
uses schema 2 and the curve store uses schema 2. Other incompatible settings are
rejected and replaced with factory defaults. Firmware identity is checked before
writing the device. Older incompatible partition layouts require the clean USB
installation described below; compatible OTA updates remain supported.

List available IDs and compatibility before building:

```sh
./scripts/dev profiles
```

Every firmware build requires both profiles. Each selector accepts an exact
built-in ID or an explicit JSON path. There is no implicit or remembered
profile selection, and an architecture-only build is rejected. `--arch`, when
also supplied, can only confirm the target derived from hardware.

The Web UI is compiled in English by default. To select it explicitly:

```sh
./scripts/dev build \
  --hardware esp32-s3-relay-x1-speaker \
  --machine la-marzocco-linea-micra \
  --webui-language EN
```

Language selection happens while the Web assets are generated; it does not add
a browser setting or embed every catalog. The flag overrides
`OPENBREWBYWEIGHT_WEBUI_LANGUAGE`, and an omitted selection always uses `en`. Codes
are case-insensitive, `_` is normalized to `-`, and a regional code tries its
exact catalog followed by its base language. English is currently the only
shipped catalog, so another base language fails instead of silently producing
English. Adding a complete locale file does not affect existing firmware until
that locale is selected.

The served Web UI is also machine-type exclusive: a build compiled for a paddle
machine ships only the paddle controls, a momentary build ships only the switch
timings and the forced-pulse action, and a reed build additionally exposes the
reed confirmation window. Controls for other machine types are not embedded at
generation time, so each firmware binary carries only the interface its machine
can use.

The wrapper preserves project diagnostics but hides ESP-IDF 6.1's known
`esp_wifi`/`wpa_supplicant` component-validation warnings. Extra-warning
reports retain their unfiltered SDK log and report project-owned warnings
separately.

The facade passes empty extra flags unless supplied; it does not reuse a saved
extra-flags preference implicitly.

For local development, use the development build profile
(`--no-auth-admin --jtag` combined):

```sh
./scripts/dev build \
  --hardware esp32-s3-relay-x1-speaker \
  --machine la-marzocco-linea-micra \
  --development
```

Omitting the profile, or passing `--release` explicitly, builds without admin
unlock and without the JTAG console. `--no-auth-admin` and `--jtag` also work
individually on top of a release build.

Machine type is derived from `interface.control` plus `interface.feedback`; a conflicting
`OPEN_BREW_BY_WEIGHT_MACHINE_TYPE` override is rejected.

| Option | Meaning |
| --- | --- |
| `OPEN_BREW_BY_WEIGHT_MACHINE_TYPE=0/1/2` | Paddle / momentary / momentary+reed; see [machine types](../README.md#machine-types). |
| `OPEN_BREW_BY_WEIGHT_ENABLE_BUZZER=0/1` | Omit / include local passive buzzer. Follows the hardware profile's `speaker.present` by default; `=0` omits it even when a speaker is present. |
| `OPEN_BREW_BY_WEIGHT_ENABLE_JTAG=1` | Development USB Serial/JTAG at boot without the GPIO4 console jumper; build it with `./scripts/dev build --jtag` (or the `--development` profile). |
| `SHOT_STOPPER_ENABLE_REMOTE_MACHINE_CONTROL=0/1` | Remote start/rinse disabled / explicit opt-in. Default is disabled. Builds without it also omit the Home remote-action controls from the served interface. |
| `OPEN_BREW_BY_WEIGHT_DEVELOPMENT=1` | Compiles administration as public: Admin and Diagnostic need no device-password session and the UI shows no lock panel. The password-unlock endpoints are not compiled in this mode. Build it with `--no-auth-admin` or the `--development` profile. Local development only — never use for an installed machine. |

### Compiler optimization and existing sdkconfig

Supported ESP-IDF firmware builds default to `CONFIG_COMPILER_OPTIMIZATION_PERF=y`
from `idf/sdkconfig.defaults`, which selects GCC `-O2` for every built-in
hardware and machine profile. After compiling, the build verifier prints the
selected optimization level (`sdkconfig: CONFIG_COMPILER_OPTIMIZATION_PERF=y`
on default builds) and fails if the configuration does not hold it.
The `Debug` setting in the root `CMakePresets.json` applies only to host tests;
it does not change firmware optimization.

ESP-IDF offers exactly four optimization levels; `-O1` and `-O3` are not
selectable and the wrapper rejects them. To compile an experiment at another
level, pass exactly one of the transient build options; omitting them keeps
the default `-O2` build:

```sh
./scripts/dev build --hardware esp32-s3-relay-x1-speaker \
  --machine la-marzocco-linea-micra
```

| Option | GCC level | Kconfig choice |
| --- | --- | --- |
| `--o0` | `-O0` | `CONFIG_COMPILER_OPTIMIZATION_NONE` |
| `--og` | `-Og` | `CONFIG_COMPILER_OPTIMIZATION_DEBUG` |
| `--o2` | `-O2` | `CONFIG_COMPILER_OPTIMIZATION_PERF` (default) |
| `--os` | `-Os` | `CONFIG_COMPILER_OPTIMIZATION_SIZE` |

The options are mutually exclusive, apply to that invocation only, and are
never persisted. They work through a generated defaults file appended to
`SDKCONFIG_DEFAULTS`; when an existing sdkconfig holds a different level, the
build recreates the configuration so the requested level takes effect, which
discards local `menuconfig` choices stored in that file. A later
build without a level option restores `-O2` the same way.
The current n16r8 image and memory baselines were measured with `-O2` and
apply to `--development -O2` builds. The historical n8r4 baselines retain
their `--development -Os` scope. Normal release builds and other optimization
levels still check the OTA partition limit, external BSS ceiling, and required
internal-memory placement; their image sizes do not establish a versioned
resource baseline.

The final verifier also rejects drift from the qualified production profile:
n8r4 uses 8 MB flash, `partitions-n8r4.csv`, and QUAD PSRAM; n16r8 uses 16 MB
flash, `partitions-n16r8.csv`, and OCT PSRAM. Both require DIO/80 MHz flash,
80 MHz PSRAM, a 32 KiB internal reserve, a 2 KiB malloc threshold above which
`malloc()` prefers PSRAM, 64 KiB MMU pages, rollback support,
mDNS dynamic responder allocations in PSRAM — the mDNS task stack follows the
variant: PSRAM on n8r4, internal RAM on n16r8 because flash core dumps cannot
read a stack in cache-backed PSRAM — the pinned boot/task/interrupt watchdog
and panic settings, and the GPTimer ISR handler in IRAM. Other application,
NimBLE/VHCI, HTTP, persistence, control, and flash-writing stacks remain
internal. These checks verify current hardware settings; they do not retune
clocks, partitions, or watchdog durations.

N16R8 builds map flash code and read-only data into PSRAM at startup and
execute from there, reserving roughly 1.9 MiB of PSRAM ahead of the heap.
N8R4 builds keep this option disabled. Flash operations still disable both
caches while they run, so this mapping does not change which code may run
during a write. An existing N16R8 build tree is regenerated when its selected
defaults change. A successful build verifies configuration and memory limits;
only an on-device comparison can establish whether loop gaps improve.

Each build compares its selected repository defaults and build profile with the
last verified build of that variant. If an input changed, was added, or was
removed, it regenerates `sdkconfig` and checks the effective configuration
before accepting the firmware image. An unchanged variant keeps its existing
configuration for incremental builds. Regeneration discards local `menuconfig`
choices in that variant, so record any custom choices before changing defaults.
Inspect one current tree with:

```sh
grep '^CONFIG_COMPILER_OPTIMIZATION' \
  build-idf/esp32-s3-relay-x1-speaker--rancilio-silvia-pro-x/sdkconfig
```

To restore repository defaults manually after changing `menuconfig`, rebuild
the selected variant with `--force-sdkconfig-regenerate`. This discards its
local `menuconfig` choices without cleaning the whole build tree:

```sh
./scripts/dev build --hardware esp32-s3-relay-x1-speaker \
  --machine la-marzocco-linea-micra --force-sdkconfig-regenerate
```

Use the directory produced by the exact selected pair. The regeneration flag
applies only to commands that include `build`; standalone flash, OTA, and
monitor reject it. Do not add optimization
flags through `--flags`; the supported optimization contract is the Kconfig
selection above, which the build verifier checks. The `menuconfig` route for
the optimization level is gone: the wrapper recreates the configuration
whenever the level differs from the requested one.

Other choices in an existing IDF `sdkconfig` are retained until selected build
inputs change or regeneration is requested. A mismatch in a required production
setting stops the build and identifies the setting; use the regeneration flag
to restore defaults after a local `menuconfig` edit.
Omitting a macro does not always mean its feature is off; explicit flags
override matching choices. Review Diagnostic build identity and options before
installation.

The build renders the selected catalog into
`src/OpenBrewByWeightWebAssetsGzip.h`, generates version identity and
`build-idf/<hardware-id>--<machine-id>/openbrewbyweight.bin`, then checks image and
memory budgets. Use only the image for the intended profile pair. The supported partition layouts have
two app slots; arbitrary 4 MB layouts cannot hold this firmware.

The n16r8 layout reserves 640 KiB for a temporary ESP-IDF core dump and
1,408 KiB for two saved crash records. Its unused FFAT area is 7,128 KiB
(`0x6F6000` bytes). Both layouts reserve 816 KiB for shot curves. The n8r4
layout keeps its existing 64 KiB core-dump
partition but does not enable persistent crash capture. On n16r8, the mDNS
task stack is internal so that stack remains available to a core dump.

Build the supported built-in pairs listed in
[Build profiles](BUILD_PROFILES.md#capability-matching) with
`./scripts/dev build`. Release images disable the JTAG console and remote
machine control at compile time; each build leaves its named `.bin` and
archive under `build-idf/` and `artifacts/firmware/`.

## 6. Flash (USB)

Proceed only after reviewing the image, board, wiring and applicable
[bench checks](MANUAL_TEST_PLAN.md). Keep the machine activation circuit
disconnected for initial verification.

Connect a USB **data** cable. Use BOOT + RST for ROM download if the app exposes
no port. App serial monitoring needs the
[GPIO4 jumper or a JTAG build](HARDWARE.md#usb-console-jumper).

Replace the port below with the detected controller port:

```sh
./scripts/dev flash --confirm --port /dev/cu.usbmodem2101 \
  --hardware esp32-s3-relay-x1-speaker --machine la-marzocco-linea-micra
```

To build and install the exact result in one command, put the stages before
their options:

```sh
./scripts/dev build flash --confirm \
  --hardware esp32-s3-relay-x1-speaker \
  --machine la-marzocco-linea-micra \
  --port /dev/cu.usbmodem2101
```

Add `monitor` to open the serial console only after both earlier stages pass:

```sh
./scripts/dev build flash monitor --confirm \
  --hardware esp32-s3-relay-x1-speaker \
  --machine la-marzocco-linea-micra \
  --port /dev/cu.usbmodem2101 --speed 115200
```

Linux commonly uses `/dev/ttyACM0` or `/dev/ttyUSB0`. Build first whenever
sources, options, or the Web UI language change: the installer never rebuilds
or relabels the selected image. Successful transfer still requires post-boot
and electrical verification.

The installer reads the partition-table sector first. Project builds always use
the existing `flash_args`, which transfers the bootloader, partition table,
initial OTA metadata and application without invoking a build. `--no-check`
only skips local identity verification. An external `--image` still replaces
app0 only on a readable installed layout.

### Partition-layout updates

### Curve-layout transition

The timestamped curve format requires a one-time USB installation of the full
project build. Build for your hardware and machine, then use the ordinary USB
flash command without `--erase-all`:

```sh
./scripts/dev flash --confirm --port /dev/cu.usbmodem2101 \
  --hardware esp32-s3-relay-x1-speaker --machine la-marzocco-linea-micra
```

For the exact preceding project layout, the installer reports that old curves
will start empty and erases only the new curve region. It preserves settings,
Wi-Fi credentials, presets, calibration, shot summaries, activation history,
both application slots and crash storage. This consumes previously unused,
unmounted filesystem space. After this installation, ordinary OTA updates
remain available. App-only `--image` and OTA cannot change the partition table.
Any other incompatible layout is rejected; review its data-loss consequences
before explicitly choosing a clean installation.

The scale-profile partition uses the same one-time mechanism: coming from the
current curve layout, the installer erases only the new 260 KiB profile region
(previously reserved, unmounted filesystem space) and reports that saved scale
profiles start empty. Nothing else on the flash changes.

### Other clean-install cutovers

The current settings contract is schema 2 and preserves same-layout schema-1
settings on upgrade; that upgrade does not require `--erase-all`. Other
incompatible settings contracts require a clean installation. An installed 20 KiB NVS layout,
or a current layout without the dedicated
816 KiB `shotcurve` partition or the 32 KiB `shotlog` and `history` partitions,
or an n16r8 layout without the new crash-history area,
needs a one-time clean USB installation. A normal flash refuses an incompatible
layout. **The following erases both firmware
slots and all saved data:** settings, Wi-Fi credentials and password, recipes
and presets, calibration, scale preferences, shot history and last shot. There
are also no retained crash records after this installation. Settings and
curves start from factory defaults without migration.

```sh
./scripts/dev flash --confirm --port /dev/cu.usbmodem2101 \
  --hardware esp32-s3-relay-x1-speaker --machine la-marzocco-linea-micra \
  --erase-all
```

Record the settings you need before reinstalling. Do not combine `--erase-all`
with an external `--image`; the project build outputs are required to write the
bootloader, new partition table, initial metadata and application. An app-only
image cannot activate a changed partition table.

## 7. Serial monitor and first setup

```sh
./scripts/dev monitor --port /dev/cu.usbmodem2101 --speed 115200
```

Exit with **Ctrl+]**. Send `HELLO` to check command access even when debug
logging is off. See [USB CLI](SERIAL_CLI.md) for troubleshooting and commands.

Verify boot identity, configured machine type and relay behavior, then continue
with [First setup and daily use](GETTING_STARTED.md).

## 8. Update over Wi-Fi (OTA)

After installation, follow [OTA](features/ota.md) for upload, verification,
commit, confirmation and recovery. OTA cannot migrate the partition table.

Build and update the same profile in one command:

```sh
./scripts/dev build ota --confirm \
  --hardware esp32-s3-relay-x1-speaker \
  --machine la-marzocco-linea-micra \
  --host 192.168.1.50 \
  --yes --wait-for-confirmation
```

`--yes` accepts the commit question; `--wait-for-confirmation` independently
verifies the rebooted image. See the [complete `dev` examples](SCRIPTS.md) for
standalone and combined build, flash, OTA, and monitor commands.

## One supported command interface

`./scripts/dev` is the only supported public firmware command. The old direct
IDF stage aliases and combination wrappers were removed. Focused shell files
under `scripts/internal/` are private implementation details.

## Optional static analysis

Use [Static analysis](STATIC_ANALYSIS.md) when requested or required by the
validation gate. It lists prerequisites, tool behavior and failure meanings.

## Firmware version

`VERSION` supplies the release number; the build adds the git revision and a
dirty marker when applicable, and rejects an absent or invalid commit ID
instead of producing `unknown`. The Web UI footer and boot output
identify the resulting version.

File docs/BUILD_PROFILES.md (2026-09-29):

# Hardware and machine build profiles

Build profiles describe one complete Open Brew by Weight installation at compile time.
They separate facts about the assembled controller from facts about the coffee
machine connected to it:

| Profile | Owns | Does not own |
| --- | --- | --- |
| Hardware | ESP32 target and memory, GPIO assignments, electrical levels, relay contact and drive, installed peripherals | Coffee-machine gestures and factory settings |
| Machine | Manufacturer and model, switch topology, available feedback, factory settings | Controller pinout, relay polarity, speaker presence |
| CLI flags | Development features and deliberate per-build overrides or additions | The source-of-truth identity of either selected profile |

Profiles are version-controlled JSON files under `config/hardware/` and
`config/machines/`. They are independent and have no inheritance: each file
must completely describe its side of the installation. A role that is not
installed is written explicitly as `{ "present": false }`; it is never implied
by an omitted key or placeholder GPIO.

## Naming and available profiles

File names and `id` values use lowercase kebab-case. A hardware capability is a
suffix, so the speaker-equipped assembly is named
`esp32-s3-relay-x1-speaker.json`. This is easier to use in paths and generated
artifact names than spaces, `_w_`, or `+`, while the human-readable name remains
in `display_name`.

The initial profiles are:

| File | Meaning |
| --- | --- |
| `config/hardware/esp32-s3-relay-x1-speaker.json` | ESP32-S3 Relay X1 assembly, N16R8, passive speaker, current Open Brew by Weight pinout |
| `config/hardware/esp32-s3-relay-x1-speaker-reed.json` | Same controller assembly with the reed input physically installed on GPIO13 |
| `config/machines/rancilio-silvia-pro-x.json` | Rancilio Silvia Pro X, momentary button without machine-state feedback |
| `config/machines/rancilio-silvia-pro-x-reed.json` | Rancilio Silvia Pro X, momentary button with required reed feedback |
| `config/machines/la-marzocco-linea-micra.json` | La Marzocco Linea Micra, maintained paddle input plus cloud power observation and optional wake-gesture recognition |

The Linea Micra is this project's reference machine: the command examples
throughout the documentation select the `esp32-s3-relay-x1-speaker` hardware
with the `la-marzocco-linea-micra` machine.

Every initial integration is marked `unqualified`. The JSON is a supported
build definition, not evidence that its wiring has passed the manual electrical
and machine tests.

## Selecting profiles

List the exact built-in IDs, capabilities, and compatible hardware pairs:

```sh
./scripts/dev profiles
```

Then select exactly one hardware profile and one machine profile:

```sh
./scripts/dev build \
  --hardware esp32-s3-relay-x1-speaker \
  --machine la-marzocco-linea-micra
```

Each selector accepts either an exact built-in ID or an explicit JSON path.
IDs are not fuzzy-matched. Both options are mandatory for every firmware build;
there is no architecture-only build, implicit default, or remembered previous
pair. They may also come from `OPENBREWBYWEIGHT_HARDWARE` and
`OPENBREWBYWEIGHT_MACHINE`, but neither selection is saved in `.openbrewbyweight`.
The deprecated `--hardware-config` / `--machine-config` flags and corresponding
`*_CONFIG` environment variables remain temporary aliases and print a warning.

`--arch` is not a board selector. If supplied alongside both profiles, it can
only confirm the architecture derived from hardware; a different value fails
before compilation. Analysis tools that inspect an existing compilation
database may still use `--arch` and `--build-dir`.

The resolver performs these operations in order:

1. Parse both JSON files and reject missing, unknown, or invalid fields.
2. Apply supported `OPEN_BREW_BY_WEIGHT_*` definitions from `--flags` to a copy of the
   profile data.
3. Validate the complete resolved hardware, machine, GPIO ownership, and
   cross-profile compatibility.
4. Generate the build header and resolved manifest.
5. Compile in an isolated directory for the `<hardware>--<machine>` variant.

No flash, OTA upload, or hardware action is part of `build`.

### Capability matching

Profiles do not name or depend on one specific counterpart. The hardware
profile provides physical capabilities through each role's `present` value;
the machine profile consumes them through its selected interface. The resolver
matches the two contracts:

| Machine requirement | Hardware capability | Result |
| --- | --- | --- |
| `feedback: "reed"` | `reed.present: true` | Valid momentary+reed build (`OPEN_BREW_BY_WEIGHT_MACHINE_TYPE=2`) |
| `feedback: "reed"` | `reed.present: false` | Hard error before CMake: required feedback is absent |
| `feedback: "none"` | `reed.present: false` | Valid momentary-only or paddle build |
| `feedback: "none"` | `reed.present: true` | Valid; the extra passive input is compiled as unused by that machine topology |

This keeps electrical facts in hardware and behavioral facts in the machine.
The machine profile never owns a reed GPIO, and the hardware profile never
selects momentary or paddle behavior. Each machine profile declares its
compatible hardware profiles in its `hardware` list, and the resolver rejects
any other pairing. Automated validation builds the supported built-in
pairs with `-O2`:

```text
esp32-s3-relay-x1-speaker       + rancilio-silvia-pro-x
esp32-s3-relay-x1-speaker-reed  + rancilio-silvia-pro-x-reed
esp32-s3-relay-x1-speaker       + la-marzocco-linea-micra
```

## Common profile identity

Both JSON types start with these fields:

| Field | Contract |
| --- | --- |
| `schema_version` | JSON contract version. The only supported value is `1`. |
| `id` | Stable lowercase kebab-case identifier, at most 63 characters. It becomes part of build paths and firmware identity. |
| `display_name` | Human-readable name, at most 63 characters. |
| `compatibility_revision` | Positive revision from 1 to 65535. Increment it when a change must make old and new OTA images incompatible. |

Profile objects are strict: unknown fields fail validation. Text must be
non-empty, at most 63 characters, and cannot contain control characters, `"`,
or `\`. Identity comes from `id` plus `compatibility_revision`; changing only
`display_name` does not create a new OTA compatibility identity.

## Hardware profile contract

The complete current hardware profile is:

```json
{
  "schema_version": 1,
  "id": "esp32-s3-relay-x1-speaker",
  "display_name": "ESP32-S3 Relay X1 with speaker",
  "compatibility_revision": 1,
  "metadata": {
    "product_url": "https://aliexpress.com/item/1005011880181624.html",
    "identifiers": ["303E32S3DC2", "5437314A_Y1248-250908"]
  },
  "target": { "chip": "esp32s3", "memory_profile": "n16r8" },
  "activator": {
    "gpio": 21,
    "active_level": "low",
    "pull": "up",
    "debounce_ms": 30
  },
  "relay": {
    "gpio": 2,
    "contact_type": "normally_open",
    "closed_level": "high",
    "open_level": "low"
  },
  "scale_status_led": { "present": true, "gpio": 1, "active_level": "high" },
  "speaker": { "present": true, "type": "passive_pwm", "gpio": 14 },
  "usb_console_jumper": {
    "present": true,
    "gpio": 4,
    "active_level": "low",
    "pull": "up",
    "sample_at": "boot"
  },
  "reed": { "present": false },
  "external_safety": { "present": false }
}
```

The reed-equipped variant remains a separate complete hardware profile. Its
identity ends in `-reed`, and its physical reed declaration is:

```json
"reed": {
  "present": true,
  "gpio": 13,
  "active_level": "low",
  "pull": "up",
  "debounce_ms": 30
}
```

All other roles are still written explicitly in that file; this excerpt only
highlights the capability that differs from the preceding complete example.

### Traceability metadata

`metadata` is a required but intentionally open JSON object. Its contents are
not schema-validated: maintainers may add fields such as `brand`, `author`,
`sku`, `identifiers`, `links`, fabrication notes, or nested objects without
changing the profile schema or resolver. The complete object is copied into the
resolved `build-profile.json`; it does not generate firmware macros, appear in
Diagnostic, or participate in OTA compatibility. This keeps provenance and
procurement references useful without making metadata changes incompatible with
an installed image.

The two initial X1 profiles refer to the same relay module, so both contain the
same product URL and identifiers `303E32S3DC2` and
`5437314A_Y1248-250908`. Because the resolver deliberately treats this object as
opaque data, maintainers must review it normally. Do not store access tokens,
account-specific URLs, or other secrets in profile metadata.

### Target, input, and relay

| Object / field | Values and behavior |
| --- | --- |
| `target.chip` | Currently `esp32s3`. |
| `target.memory_profile` | Currently `n16r8`: 16 MB flash and 8 MB OPI PSRAM. This describes capacity, not the physical board or pinout. |
| `activator.gpio` | Physical brew-switch input, GPIO 0–48. |
| `activator.active_level` / `pull` | Current driver requires `low` with internal pull `up`. |
| `activator.debounce_ms` | Input debounce, 1–99 ms. |
| `relay.gpio` | Relay drive output, GPIO 0–48. |
| `relay.contact_type` | Currently only `normally_open`. K1 is open at startup and on safety failure. |
| `relay.closed_level` / `open_level` | Output levels that energize/close and release/open K1. They must differ. The X1 assembly closes on `high` and opens on `low`. |

`contact_type` describes the physical contact path; `closed_level` and
`open_level` describe the controller signal. Keeping both avoids assuming that
a normally-open contact is necessarily driven by a particular logic level.

### Installed and absent resources

Every optional physical role has a required `present` boolean. If it is `true`,
all fields for that role are mandatory. If it is `false`, `present` must be the
only field; do not retain a GPIO for hardware that is not installed.

| Role | Fields when present | Current constraints |
| --- | --- | --- |
| `scale_status_led` | `gpio`, `active_level` | Level is `low` or `high`. |
| `speaker` | `type`, `gpio` | Type is currently `passive_pwm`. Presence enables the local buzzer; `-DOPEN_BREW_BY_WEIGHT_ENABLE_BUZZER=0` omits it. |
| `usb_console_jumper` | `gpio`, `active_level`, `pull`, `sample_at` | Current driver requires active-low, pull-up, sampled at `boot`; GPIO 0, 45, and 46 are rejected as strapping pins. |
| `reed` | `gpio`, `active_level`, `pull`, `debounce_ms` | Current driver requires active-low and pull-up; debounce is 1–99 ms and must equal the activator debounce. |
| `external_safety` | `heartbeat_gpio`, `heartbeat_idle_level`, `feedback_gpio`, `feedback_closed_level`, `feedback_pull`, `heartbeat_period_ms`, `feedback_settle_ms` | Current driver requires low heartbeat idle and feedback pull-up; periods are 10–1000 ms and 1–1000 ms respectively. |

All present roles own their GPIOs exclusively. A collision between any input,
relay, LED, speaker, jumper, reed, or external-safety pin fails before CMake or
the compiler runs.

## Machine profile contract

A machine profile adds these required identity and integration fields:

| Field | Contract |
| --- | --- |
| `brand` | Manufacturer stored separately, for example `Rancilio` or `La Marzocco`. |
| `model` | Product model stored separately, for example `Silvia Pro X` or `Linea Micra`. |
| `integration_revision` | Kebab-case description of the reviewed integration. Initial profiles end in `unqualified` until physically tested. |
| `integration` | Compile-time digital integration: `none` or the allow-listed `linea_micra_cloud`. This is explicit and is never inferred from brand, model, ID, or display name. |
| `interface.control` | `momentary` or `paddle`. |
| `interface.feedback` | `none` or `reed`. Paddle currently permits only `none`. |
| `factory_defaults` | Defaults appropriate to the selected control topology. |

The brand, model, and integration are not parsed from the file name, ID, or
display name. Brand and model are compiled separately and shown separately in
Diagnostic. An unknown integration fails profile resolution; adding one
requires its own isolated implementation and build registration.

### Momentary machines

Silvia Pro X uses the historical momentary source defaults:

```json
{
  "schema_version": 1,
  "id": "rancilio-silvia-pro-x",
  "display_name": "Rancilio Silvia Pro X",
  "compatibility_revision": 1,
  "brand": "Rancilio",
  "model": "Silvia Pro X",
  "integration_revision": "momentary-only-v1-unqualified",
  "integration": "none",
  "interface": { "control": "momentary", "feedback": "none" },
  "factory_defaults": {
    "operational_wall_ms": 50000,
    "momentary": {
      "start_edge": "press",
      "stop_pulse_ms": 300,
      "max_single_press_ms": 1000,
      "assume_idle_on_scale_connect": true,
      "shot_reaction_timeout_s": 0
    },
    "quick_rinse": { "enabled": false, "gesture_ms": 1000, "duration_ms": 4000 }
  }
}
```

| Field | Accepted values | Meaning |
| --- | --- | --- |
| `operational_wall_ms` | 5000–60000 | Logical operational limit seeded for the machine. |
| `start_edge` | `press`, `release` | Edge on which firmware applies logical Start/Stop. It does not change the normal physical relay mirror. |
| `stop_pulse_ms` | 50–1000 | Pulse used to request an automatic stop. Historical default: 300 ms. |
| `max_single_press_ms` | 100–5000 | Longest hold treated as one logical press. Historical default: 1000 ms. |
| `assume_idle_on_scale_connect` | Boolean | Seeds the button-only inference behavior. Historical default: `true`. |
| `shot_reaction_timeout_s` | `0`, or 3–30 | Quiet-flow inference timeout. `0` preserves the compiled historical fallback, currently 12 seconds. |
| `reed_confirm_timeout_ms` | 200–5000 | Required only when feedback is `reed`; omitted when feedback is `none`. |

The complete reed machine profile differs in identity, selects reed feedback,
and adds the historical 1000 ms confirmation timeout:

```json
{
  "schema_version": 1,
  "id": "rancilio-silvia-pro-x-reed",
  "display_name": "Rancilio Silvia Pro X with reed",
  "compatibility_revision": 1,
  "brand": "Rancilio",
  "model": "Silvia Pro X",
  "integration_revision": "momentary-reed-v1-unqualified",
  "integration": "none",
  "interface": { "control": "momentary", "feedback": "reed" },
  "factory_defaults": {
    "operational_wall_ms": 50000,
    "momentary": {
      "start_edge": "press",
      "stop_pulse_ms": 300,
      "max_single_press_ms": 1000,
      "assume_idle_on_scale_connect": true,
      "shot_reaction_timeout_s": 0,
      "reed_confirm_timeout_ms": 1000
    },
    "quick_rinse": { "enabled": false, "gesture_ms": 1000, "duration_ms": 4000 }
  }
}
```

It only resolves with the hardware profiles the machine profile declares; the
reed machine requires hardware whose reed role is present. For example:

```sh
./scripts/dev build \
  --hardware esp32-s3-relay-x1-speaker-reed \
  --machine rancilio-silvia-pro-x-reed
```

### Paddle machines

Linea Micra uses the historical paddle source defaults, with Quick rinse enabled
for this machine profile:

```json
{
  "schema_version": 1,
  "id": "la-marzocco-linea-micra",
  "display_name": "La Marzocco Linea Micra",
  "compatibility_revision": 1,
  "brand": "La Marzocco",
  "model": "Linea Micra",
  "integration_revision": "paddle-v1-unqualified",
  "integration": "linea_micra_cloud",
  "interface": { "control": "paddle", "feedback": "none" },
  "factory_defaults": {
    "operational_wall_ms": 50000,
    "paddle": {
      "mode": "natural",
      "return_reminder": {
        "enabled": true,
        "interval_ms": 30000,
        "max_duration_ms": 900000
      }
    },
    "quick_rinse": { "enabled": true, "gesture_ms": 1000, "duration_ms": 4000 }
  }
}
```

| Field | Accepted values | Meaning |
| --- | --- | --- |
| `paddle.mode` | `natural`, `original`, `auto` | Initial paddle behavior. Historical default: `natural`. |
| `return_reminder.enabled` | Boolean | Enables the reminder while the paddle remains ON after automatic stop. |
| `return_reminder.interval_ms` | 5000–120000 | Reminder interval. Current factory default: 30000 ms. The Web selector offers OFF, 15, 30, 60, and 120 seconds. |
| `return_reminder.max_duration_ms` | At least 60000 and the interval, up to 3600000 | Maximum reminder duration. Historical default: 900000 ms. |

Both topologies require `quick_rinse`: `enabled` is Boolean, `gesture_ms` is
100–5000, and `duration_ms` is 500–10000 without exceeding
`operational_wall_ms`. The
historical timing defaults are a 1000 ms gesture and 4000 ms duration. It is
disabled in the Rancilio profiles and enabled in the Linea Micra profile.

## Defaults, persistence, and factory reset

Machine values are factory defaults, not a forced runtime policy. They seed a
new installation and are restored by factory reset. Valid settings already in
persistent storage continue to win after a normal boot, so
changing a profile default does not silently rewrite an existing user's setup.

Topology and physical wiring are compile-time choices. A persisted setting
cannot turn a paddle build into momentary, add a missing reed, move a GPIO, or
reverse relay polarity.

## CLI override and extension rules

The JSON supplies the base configuration. Definitions in `--flags` are parsed
next and supported values update the resolved manifest before its final
validation. Other compiler definitions and warnings are passed through as
additions. For example:

```sh
./scripts/dev build \
  --hardware esp32-s3-relay-x1-speaker \
  --machine la-marzocco-linea-micra \
  --flags "-DOPEN_BREW_BY_WEIGHT_RELAY_GPIO=3"
```

Supported physical overrides cover activator, relay, present LED/speaker/USB
jumper/reed/external-safety GPIOs, their supported active levels, and timing
values. Supported machine-default overrides cover the operational wall, rinse
settings, paddle mode/reminder settings, and momentary pulse, press, edge,
idle-assumption, reaction, and reed-confirmation settings.

The following safety rules still apply after overrides:

- Profile IDs, compatibility revisions, brand, and model cannot be overridden.
- Presence flags cannot contradict the physical profile. A GPIO cannot be
  assigned to a role whose `present` value is `false`.
- Overridden GPIOs are checked again for ownership collisions.
- `OPEN_BREW_BY_WEIGHT_MACHINE_TYPE` may only repeat the type implied by the machine
  profile; a conflicting value fails.
- A machine requesting reed feedback requires hardware with `reed.present=true`.
- Buzzer support follows `speaker.present`; forcing `=1` without a speaker fails.
- The architecture cannot contradict `target`.

Development mode, JTAG, remote machine control, buzzer enablement, warnings,
and other non-physical build switches remain CLI concerns. The `--release`
profile (the default) compiles with neither admin unlock nor the JTAG console;
the `--development` profile combines `--no-auth-admin --jtag`. `--no-auth-admin`
adds `OPEN_BREW_BY_WEIGHT_DEVELOPMENT=1` for that run without saving it and
conflicts with an explicit `OPEN_BREW_BY_WEIGHT_DEVELOPMENT=0`. These profile
and unlock switches must never be added to a JSON profile.

## Generated files and runtime identity

A named build uses:

```text
build-idf/<hardware-id>--<machine-id>/
```

Its `generated/` directory contains:

- `build-profile.json`: the fully resolved hardware and machine data after
  supported overrides;
- `OpenBrewByWeightBuildProfileGenerated.h`: compile-time macros consumed by the
  firmware, including `OPEN_BREW_BY_WEIGHT_ENABLE_BUZZER` from `speaker.present`;
- `OpenBrewByWeightVersion.h`: firmware version plus architecture and profile
  compatibility identities.

The build also copies a named binary to
`openbrewbyweight-<hardware-id>--<machine-id>.bin` inside the same build directory.
Generated files are build outputs; edit source profiles instead of editing
them.

The firmware reports `hardwareProfile`, `machineProfile`, `machineBrand`, and
`machineModel` in status/build information. Diagnostic's **Compilation** section
shows the same resolved identity. OTA identity uses the architecture and
`<id>-r<compatibility_revision>` for both profiles; an image built for a
different hardware or machine compatibility identity is rejected even when its
ESP32 memory configuration is identical.

Architecture-only firmware builds are rejected because `n16r8` does not identify
a physical board, pinout, relay circuit, or coffee machine.

## Adding or changing a profile

1. Copy the closest profile of the same type and give it a new stable kebab-case
   file name and `id`.
2. Describe every field, including absent physical roles. Do not copy a pinout
   or machine topology based only on a product-family name.
3. Record brand and model separately for a machine. Use an `unqualified`
   integration revision until the exact circuit and machine revision pass the
   manual acceptance plan.
4. Increment `compatibility_revision` whenever the same ID changes in a way
   that must block cross-installation OTA. Use a new ID when it represents a
   different assembled controller or machine integration.
5. Run the profile contract test and an exact named build:

   ```sh
   ./scripts/dev test tooling
   ./scripts/dev build \
     --hardware <hardware-id> \
     --machine <machine-id>
   ```

6. Classify the complete change and run the required validation gate. Hardware
   qualification, flashing, relay operation, and HIL require separate explicit
   authorization and evidence.

Related references: [Build](BUILD.md), [script reference](SCRIPTS.md),
[hardware installation](HARDWARE.md), [momentary behavior](settings/momentary.md),
[paddle behavior](settings/paddle.md), and [OTA image identity](features/ota-image-identity.md).

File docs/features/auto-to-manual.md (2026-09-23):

# A→M time guard

Time guard for automatic brew-by-weight shots that **lose the scale**
mid-extraction. **On by default.**

A→M means auto-to-manual: weight stop is suspended, but the shot is still
running. The guard requests a stop on a shorter deadline while reconnection continues.
Paddle builds open the relay; momentary builds request a stop pulse subject to
[machine-state and safety conditions](../settings/momentary.md#stopping-and-time-limits).

## When it applies

Automatic brew-by-weight shots only. It does **not** apply to shots that
start as manual (`MANUAL_NO_SCALE`), timer-only (BBW off), or rinses.

When BLE drops or **notifications stop arriving**, weight control pauses.
A steady weight is not a disconnect: fresh weight notifications still count
as a live stream even if the brew logic rejects a particular sample. The firmware
keeps trying to reconnect for the **whole** cycle. If the scale returns with
three coherent samples, weight stop resumes (including Fast or Slow, if
enabled) and A→M enforcement clears. A later disconnect in the same cycle
reuses the same deadline counted from cycle start.

There is no permanent lockout to manual after a fixed reconnect window.
Reconnect stays preferred.

## Parameters

Active preset. The ON/OFF switch is also on **Home → Quick Settings**
(read-only when brew by weight is off).

| Setting | Default | Range / notes | Effect on the shot |
| --- | --- | --- | --- |
| **Enable A→M time guard** | ON | ON / OFF | Master switch. OFF: if the scale never returns, the shot runs until paddle OFF or the machine circuit / 60 s wall. |
| **Limit mode** | Auto | Auto / Manual | **Auto** uses a trend of the last five eligible BBW shot durations. **Manual** uses a fixed number of seconds. |
| **Manual limit (s)** | 32 s | 10 s … Max BBW time | Used when Limit mode is Manual. |
| **Trend (s)** | ~32 s | Read-only | Current Auto prediction. Always shown. |
| **Baseline duration (s)** | 32 s | — | Seed for **Reset A→M samples** (five equal values). Also the factory default for Manual limit. |

Deadline = cycle start + limit. The limit is computed once when an automatic
brew is confirmed. Enforcement starts on the first scale-loss suspend after
arming.

The live panel shows `Off` / `Idle` / `Armed` / `A→M · Ns`. History records
`stop_detail = auto_to_manual` and `cut_type = limit`.

## Duration samples

Successful shots feed a ring of five durations, whether the guard is on or
not:

- Total shot duration; error ≤ 10 % vs goal; not Fast/Slow extended; not a
  rinse; not stopped by this guard; post-drip weight available.
- Auto and manual shots can qualify when weight/error criteria are met.
- A fresh device starts with five logical **32 s** samples.

## Example

An automatic Double loses Bluetooth at 12 s. Trend limit is 32 s. The
firmware keeps reconnecting, but if the scale is still gone at 32 s from
start, the controller requests stop. If the scale comes back at 20 s with three good samples,
weight stop resumes and enforcement clears. A later disconnect reuses the
original 32 s deadline, rather than starting another 32-second allowance.

Related: [Brew by weight](brew-by-weight.md), [Alerts](../alerts.md)
(ATM / manual-no-scale).

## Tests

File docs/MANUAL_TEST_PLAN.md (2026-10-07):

# Manual Test Plan

These are acceptance procedures, not instructions to operate hardware
automatically. Start on an isolated bench. Connect a live machine only after
the applicable electrical checks pass.

Memory-placement changes require M39/M81/M90 evidence on both PSRAM targets.
Exercise profiler start/stop, malformed and concurrent JSON requests, repeated
settings writes and webhook completion while flash operations are active.
Confirm no cache-disabled access panic, corruption, lost persistence completion
or unexplained allocation-failure delta; record internal/PSRAM free, minimum
and largest blocks before and after warm-up. Capture all task stack margins
in bytes, using short profiler runs for tasks absent from continuous health.
Allocation-failure injection in host tests does not replace this target gate.

## Select and record a run

For the Home shot stream, open Home during an activation and confirm that its
curve includes earlier readings. At cutoff, duration must freeze while drip
readings continue. Compare final yield, duration, first drop and curve with
Stats. Observe a rinse or short activation, reconnect within 30 seconds of
resolution, and verify the original expiry; a reload must open Stats' latest
shot. Start another activation during drip or temporary retention and verify
that late results cannot replace it. Repeat with two browsers, background and
resume, inactivity, scale loss and late retare. Use disposable fixtures for
rating, deletion and clearing. Check that Stats, History and OTA stay responsive
with four sockets, unchanged idle streams send no card data, and reconnects
recover internal/PSRAM free, minimum and largest-block margins.

Use [VALIDATION.md](../VALIDATION.md) to select the required gate. Record
firmware/git version, board revision and PSRAM architecture, compile flags,
machine/switch type, scale model/firmware, settings, measured timings and
pass/fail evidence. A missing prerequisite is not a pass.

Unless a row says otherwise, workflow examples assume Natural paddle mode,
Quick rinse off, and a usable scale. Adapt only through the documented
[machine-type contract](settings/momentary.md#stopping-and-time-limits);
relay-open and group-stopped are not interchangeable on momentary machines.

Existing IDs are retained; the formerly duplicated USB M66 is now **M66-USB**,
while drip-delay M66 keeps its ID. Current release requirements are defined by
[scheduling](SCHEDULABILITY.md), [resource budgets](P2_RESOURCE_BUDGETS.md),
and [target traces](P2_TARGET_TRACE.md), not by a historical pass.

## Sections

- [Boot, electrical safety and reset](#boot-electrical-safety-and-reset)
- [Brewing, cup, scale and presets](#brewing-cup-scale-and-presets)
- [Network, Web UI and access](#network-web-ui-and-access)
- [Recovery](#recovery)
- [OTA and runtime qualification](#ota-and-runtime-qualification)
- [Momentary behavior and scale discovery](#momentary-behavior-and-scale-discovery)
- [Historical cutover evidence](#historical-cutover-evidence)

## Boot, electrical safety and reset

| ID | Procedure | Expected result |
| --- | --- | --- |
| M01 | Power the controller with the paddle OFF. | Relay is open at boot; after debounce, state is `READY`. |
| M02 | Power it with paddle ON, then release it. | Machine circuit stays open until a stable OFF is detected. |
| M18 | Reset or remove controller power while measuring relay COM/NO. | Contact remains open; there is no unintended close pulse. |
| M20 | Open the Web UI status with the external safety macros disabled. | `Circuit safety` reports timers and WDT ready, plus `external not configured`; this build is identified as software-only protection. |
| M21 | On an isolated bench load, use an instrumented test build to stop `loopTask` immediately after machine circuit closes. Do not attach OpenOCD during the measurement. | GPTimer/K2 opens the machine circuit within the configured measured limit and TWDT reboots the board within its 5 s timeout; the boot never recloses the machine circuit. |
| M22 | Freeze only `scale_worker` while leaving control responsive. | Its own TWDT subscription causes a reboot within 5 s; machine circuit opens on or before reset and does not resume afterward. |
| M23 | Freeze only `network_manager` while leaving control responsive. | Its own TWDT subscription causes a reboot within 5 s; no network task can directly restart or close the machine circuit. |
| M24 | Build with K2/feedback enabled, disconnect the isolated feedback input, and request a close. | Feedback fails to confirm within 100 ms; K1 opens and safety enters `LOCKOUT`. |
| M25 | Force feedback to the CLOSED level before boot and before a close request. | The supervisor reports `FEEDBACK_STUCK_CLOSED`, remains in `LOCKOUT`, and never energizes K1. |
| M26 | While K2 is energized, hold heartbeat permanently LOW, then permanently HIGH, and finally disconnect it. | The external detector opens K2 within its independently specified timeout in all three cases. |
| M27 | Simulate a welded K1 or shorted K1 driver using the isolated bench fixture, then remove heartbeat. | K2 still opens the series machine circuit path within its measured non-retriggerable limit. |
| M28 | Repeat M01, M02, M07, M18 and M21-M27 on ESP32-S3 N8R4 and N16R8. | Every target passes with measured timings recorded; no idle-task starvation or false WDT resets. |
| M29 | Run brownout, power-cut, Wi-Fi/RF stress and a 72 h soak followed by 10,000 relay cycles on the isolated fixture. | No spontaneous close, over-limit close, resumed cycle after reset or undiagnosed feedback mismatch occurs. |
| M37 | Factory-reset two devices, verify factory access, then change each password independently. Record only success/failure, never the secrets. | Both initially use the documented factory password. Each replacement works only on its own device; Admin/OTA/AP agree on that device's password. Replies do not echo secrets. |
| M38 | Force CPU-frequency setup, EEPROM initialization and BLE initialization failures one at a time on an instrumented build. | Frequency/safety initialization failure prevents machine circuit close; EEPROM failure uses volatile safe defaults without network persistence; BLE failure permits only local manual operation. |
| M39 | During a 72 h target-specific soak, record `/api/v1/status/admin` health fields and firmware size on every build. | Loop/task age and stack remain bounded, heap minimum/largest block do not trend toward exhaustion, drops are explained, and every `.bin` stays below the size budget. |
| M40 | Boot with the onboard GPIO1 LED wired as documented and **Blue LED while scale connected** enabled. | The LED stays LOW through boot with no scale; connecting a scale drives GPIO1 HIGH without relay movement; disconnecting returns it LOW. |
| M43b | Trigger a watchdog panic/reboot while machine circuit is closed, keep the paddle OFF after reset, and open every WebUI view. | The panic callback opens the machine circuit before reboot and `setup()` holds it OPEN; the previous cycle does not resume. The controller reaches normal Ready without a recovery gesture or unsafe override; WebUI configuration, rinse, and the next machine circuit cycle work normally. |
| M44 | Short or disconnect the GPIO1 LED, then repeat a normal paddle stop and the 60-second hard-limit test. | LED wiring failure cannot delay the control loop, keep machine circuit closed, or affect either hard deadline. |
| M100 | Build `esp32-s3-relay-x1-speaker` with each Rancilio machine profile. Record the resolved manifest and Diagnostic **Compile flags** values, then power/reset the isolated controller with the input active and inactive. | Diagnostic shows the exact hardware profile plus machine profile ID, brand, and model. The relay uses GPIO2, opens LOW before other initialization, closes HIGH only after readiness, and remains open through reset/failure. No absent reed GPIO is touched. |
| M102 | Turn **Admin → Firmware → Enable Open Brew by Weight** off, save, and let the controller restart. | The running pour finishes first; after restart the web UI shows only Admin with Network, Power management, Frontend, Device password, Restart, Firmware update, and Factory reset; no brew, BLE, webhook, Micra, or NTP activity occurs. |
| M103 | On an isolated bench load in compatibility mode, hold the paddle beyond the configured BBW wall and for at least 90 s; release and repeat. Repeat with the physical momentary switch on supported builds. | The relay mirrors the entire hold, including across 60 s, without a cut or open/reclose pulse. Release opens it and a new physical hold works normally. No brew session or synthetic momentary pulse is created. |
| M104 | On an isolated bench load in compatibility mode, freeze `loopTask` while the paddle is held; repeat with the configured external heartbeat fixture. Then re-enable firmware, restart and repeat the normal 60 s limit test. | Compatibility has no independent duration cutoff; TWDT/panic/reset and the configured external heartbeat retain their measured fault behavior. The relay stays open after reset with the paddle held until stable OFF. Full firmware restores its independent 60 s cap. |
| M105 | On the isolated feedback fixture in compatibility mode, hold the paddle beyond 60 s, then remove close feedback. Also repeat M24/M25 close-refusal cases. | Feedback faults still open or refuse the relay and enter LOCKOUT. Disabling the duration cap does not disable feedback supervision. |
| M106 | In compatibility mode, power-cycle the controller mid-brew with the paddle held and re-open the Web UI. Repeat with the momentary switch held on both supported switch types, and after a non-lockout relay trip. | Boot/trip keeps the relay open with no transient re-close while the activator is held. Stable OFF rearms the controller and a new hold mirrors normally; OTA and recovery remain available in compatibility mode. |
| M107 | Turn **Enable Open Brew by Weight** back on, save, and restart. | All previously saved presets, guards, scale, machine, alert, and network settings return exactly as they were before the switch was turned off. |
| M108 | Turn the switch off, then perform a factory reset from Admin or the recovery gesture. | The controller returns in full mode with factory defaults and the firmware switch back on. |
| M101 | On a fresh/factory-reset device verify every selected machine default, change several runtime settings, reboot and perform a normal OTA with the same profiles. Separately select an image with a different hardware or machine compatibility ID. | Fresh/reset settings match the JSON profile; changed settings survive reboot and matching OTA. The mismatched image is rejected before commit even when its architecture is also n16r8. |

## Brewing, cup, scale and presets

| ID | Procedure | Expected result |
| --- | --- | --- |
| M03 | With **Quick rinse** ON, from Ready turn paddle ON for less than the rinse gesture threshold, then OFF. | Rinse starts, machine circuit remains closed for configured rinse duration, then opens. With Quick rinse OFF, the same short ON→OFF is a shot, not `RINSE`. |
| M04 | Hold paddle ON past the rinse gesture with a connected scale. | State becomes `BREW` quickly (after debounce/BLE); first drops beep when coffee starts (independent of the retare window). |
| M05 | Repeat M04 with beep disabled. | Brew starts normally and no first-drops beep command is sent. |
| M06 | With Natural paddle mode and Quick rinse off, turn paddle OFF during brew/manual. | Machine circuit opens immediately; next cycle requires normal rearm. |
| M07 | On Natural paddle firmware, leave an automatic BBW cycle ON until the configured wall time. | Machine circuit opens no later than the configured limit, never later than 60 s. |
| M08 | Disconnect the scale during brew, then reconnect it and resume valid notifications. | Weight control becomes `SUSPENDED` without silently changing the workflow to manual, then returns to `ACTIVE` only after three coherent samples from the new connection generation. Verify the selected mode's physical stop and applicable hard limits; Auto/Original OFF is not a universal immediate stop. |
| M08B | With an over-the-air BLE sniffer, repeat a remote scale disconnect during connect, discovery, subscription, initialization, and an ATT write, plus a supported Bookoo power-off. Capture the GAP callback and final in-flight submission completion; for power-off, also capture the terminal shutdown write. | A submission admitted before the callback may finish; no later procedure is admitted. The full 3,000 ms quiet interval begins at that completion, or at the callback when no submission is in flight. A disconnect during the local shutdown interval restarts the full interval. Discovery resumes afterward as a fresh connection, and no old weight or command is replayed. |
| M08C | On an isolated bench, repeatedly reject heartbeat writes while the scale remains connected and sends changing weights; then stop notifications, and separately trigger real link loss. Observe retry spacing, generation, disconnect sequence, latest weight age, and machine control. | Rejected writes retain the connected generation and disconnect sequence, retries keep the protocol interval, and fresh weights continue updating. Stopped notifications still reach packet timeout. Real loss invalidates old weight and suspends weight control without an unsafe machine-circuit close. |
| M08D | On an instrumented bench build, cancel connection setup immediately before its successful GAP callback. Delay the callback beyond the quiet interval; repeat across multiple cancellation cycles and a host reset with handle reuse. | New attempts wait for cancellation acknowledgement. A raced successful connection is terminated by the owner exactly once after an accepted termination request; rejected requests retry no faster than the quiet interval. A missing callback causes no radio retry storm. Host reset releases pending cleanup and an old callback cannot terminate the replacement link. |
| M08E | On an instrumented bench, leave a scale command requiring an ATT response unanswered until its timeout, then delay the established link's GAP disconnect past the quiet interval. Repeat with a rejected termination request and with a supported Bookoo shutdown write receiving no ATT response. | The old link retains a cleanup owner; no scan or connection begins before closure is confirmed. Termination waits through shutdown silence when necessary. The eventual GAP callback restarts all 3,000 ms, its completion is logged, and no old command or weight is replayed. |
| M08F | With the machine circuit isolated, repeatedly turn a connected Bookoo off using its button and back on. Record scale/controller LED timing and command, disconnect, cleanup, and reconnect logs; include idle and pending-command cases. | The scale shuts down and powers on normally on every recorded trial. The controller's fast connecting indication clears after a failed attempt; it does not remain latched throughout shutdown silence. Recovery respects M08B/M08E and a new connection supplies fresh weights. Host tests alone do not qualify this shutdown behavior. |
| M10 | Change a workflow field during brew, rinse, and manual states. | UI is disabled and API rejects each change; current snapshot is unchanged. |
| M11 | Save valid workflow settings while Ready, restart, and reopen UI. | Values persist and apply to the next cycle only. |
| M12 | Enter a relationship-invalid timing configuration. | Server rejects the complete transaction; no field changes. |
| M19 | From Ready, set **Baseline offset**, save, press **Reset learned stop offset to baseline**, confirm, then restart. | The learned offset is reset to the configured baseline (factory default 1.5 g) and remains there; a pending post-shot analysis cannot overwrite it. |
| M33 | Disconnect or freeze the scale before its first weight, then repeat after allowing the last weight to become older than 1 s. | A cycle without initial scale authority remains manual; an automatic cycle with a stale stream publishes `STALE`/`SUSPENDED` and never uses stale weight. |
| M34 | During an automatic shot, inject NaN, one isolated abrupt sample, and then two fresh abrupt samples above 1,000 g as if pressing the scale with a finger. | Invalid/outlier data never enters regression or learning. One sample suspends control; a confirmed overload opens the machine circuit with `WEIGHT_ANOMALY`, even before ten regression samples exist. |
| M35 | Force the scale-command and event queues full while ending a shot. | Machine circuit opens immediately; the control loop never blocks. The scale STOP is retried within its bounded window and drop counters become visible. |
| M41 | Disable **Blue LED while scale connected**, connect a scale, then re-enable the setting. | GPIO1 stays LOW while the setting is off even if the scale is connected, and goes HIGH when the setting is saved on. Machine circuit behavior remains controlled by the state machine. |
| M45 | Start an automatic shot with the cup already on the scale before paddle ON. | Initial tare only; retare window runs but does not retare a stable full cup; first drops beep when coffee starts (independent of the retare window); shot stops at target weight after BBW protection ends. |
| M46 | Power-cycle the scale, reconnect, place a cup, and run the first paddle shot. | The first shot enters automatic brew; the log does not show `MANUAL_NO_SCALE` from missing fresh weight. |
| M47 | During early brew with rejections, inspect the Web UI log. | Each rejection names the reason (`slew`, `range`, etc.) and includes numeric weight context. |
| M48 | Run an automatic brew to target weight after M45 or M46. | Machine circuit opens at the BBW target after BBW protection ends (`normal_target`). |
| M49 | Start an automatic shot with the cup off the scale, then place a ~150 g cup within 1 s of brew start (a real put-down may overshoot, e.g. 160→150). Repeat with the cup at ~3 s (still inside the default 4 s retare window). | Automatic retare occurs once; **no first-drop beep** when the cup lands; shot timer does not restart; first drops beep once when coffee starts (against tare zero, even during **Post-tare grace**); shot stops at target weight after grace settle. |
| M50 | Repeat M49 with automatic retare disabled. | No retare window; BBW protection still runs from shot start. |
| M51 | During the retare window, place only a stable ~7 g object (below minimum cup weight in **Settings → Machine and scale → Cup**). | No retare; retare window expires; BBW protection continues until timeout. |
| M52 | Place a heavy cup (> target weight) during the retare window. | Shot does not stop by weight until BBW protection ends. |
| M53 | Let BBW protection timeout expire without detecting drops, then allow coffee to accumulate. | No beep at timeout; when first drops are later detected, optional beep plays once; weight stop then works normally. |
| M54 | Shorten BBW protection below retare window + 3 s in the Web UI and save. | Server rejects the transaction or clamps to the minimum; UI hint explains the rule. |
| M55 | With automatic retare off, run an automatic shot. | Retare window is skipped; BBW protection still inhibits weight stop until it ends. |
| M58 | Sign in → Settings → Brew: confirm Single/Double cards; Load Single then Double; form goal/min/rec/baseline follow the active preset without copying into a separate machine brew blob. | Active card highlights; composed status matches the preset; reboot keeps the same active id. |
| M59 | Edit Double goal, Save preset, pull a shot that learns offset; switch to Single then back to Double. | Learned offset stays on Double; Single keeps 0.5 g baseline/offset; Reset learned offset restores that preset’s baseline. |
| M60 | New → Untitled (FW Double seed 36 g / baseline 1.5); Duplicate Double → “Double copy”; Duplicate again → “Double copy 2”; rename copy inline (desktop) or dialog (phone); Delete a custom until one remains (last delete rejected). | Names and seeds match; rename persists without rewriting learned fields; cannot delete the last preset. |
| M66 | In **Settings → Machine and scale → Scales**, set **Drip delay** to 0 s, run a shot, then repeat with 3.0 s and 10.0 s while watching Last Shot/history and the scale weight after machine circuit opens. Reboot after saving and verify the selected value remains. | `status/settings.config.dripDelayMs` reports 0, 3000, and 10000 respectively. Final weight/history update on the next control loop at 0 s and only after the configured window at 3/10 s. The saved value survives reboot; starting another shot during a pending window commits the previous shot with its last-known weight. |
| M66B | With a local buzzer build, select **Buzzer only**, enable **Bullseye melody**, paste a valid RTTTL tune (≤500 characters), and save. Finish automatic, timer-only, and manual shots at the exact target; also try a brief target touch, a stable non-target weight, Scale priority, Sound alerts OFF, and disabling/re-enabling Bullseye. | The custom tune plays once after 1 continuous second of fresh exact-target samples, including before drip delay expires. It stays silent for brief/non-target runs and outside Buzzer only. Disabling makes the textarea gray/read-only without erasing it; re-enabling and rebooting restore the saved tune. Rinses never trigger it. |

## Scale profiling capacity and time estimate

Run these cases only on an explicitly authorized isolated bench; this table
does not authorize flashing, OTA, relay operation, or HIL execution.

| ID | Procedure | Expected result |
| --- | --- | --- |
| M-SP-01 | Start profiling with a connected scale. Observe elapsed time, capacity and ETA beyond three minutes while capacity remains; leave/reopen the page. | Recording continues beyond 180 s. Capacity reflects recorded data and the closing reservation. ETA appears after calibration, varies smoothly, and survives reopening the page. |
| M-SP-02 | Repeat with scales of different update rates; vary the rate of tare/cup events, then interrupt and resume scale data. | All event traffic affects capacity and ETA. The estimate may increase when traffic slows; a sustained lack of records makes it unavailable without stopping capture. Resumption recalibrates it. |
| M-SP-03 | Allow a capture to fill, then download and save/restart. Repeat with a manual stop before full. | Full capture stops automatically with one terminal record and no overwrite. A partial stop retains its actual percentage. Saving state is distinct from occupancy; once Saved, the trace and final occupancy survive restart. Machine safety behavior remains unchanged. |

## Post-drip chart acceptance

| ID | Procedure | Expected result |
| --- | --- | --- |
| M66a | With a 3 s drip delay, finish a shot and compare Home, Stats and CSV on narrow/wide screens and both themes. Reload after saving. Repeat with a scale interruption or cup removal during the delay. | Extraction remains solid and filled; recorded post-stop weights form a faint dashed, unfilled tail at their actual times, ending in a small hollow circle only when the complete last sample matches Yield. The circle stays 6 px at every chart width. Flow also continues faint, dashed and unfilled from cutoff using supported measured windows, without a final ring or invented zero. Duration and Max flow exclude drip time; CSV includes supported drip flow values. Unsupported windows remain empty, and the plot range fits drip rates. Gaps remain gaps; cup removal is not plotted as coffee. Existing saved shots without drip samples gain no invented tail. No extra labels appear. |
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

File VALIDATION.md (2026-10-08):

# Validation gates

Classify changed paths with `./scripts/dev classify [paths...]`. Unknown paths
are R3 and an override can only raise risk. Complete logs and a redacted JSON
summary are written to `artifacts/runs/`.

When several agents share this checkout, always pass the paths of your change
and read the `warning: changed path outside requested scope` lines: they name
other sessions' working-tree edits that your gate did not cover, so a clean
gate is never mistaken for a clean tree. Omitting paths classifies the whole
working tree and prints no warning.

Every change — including documentation-only edits — must be reviewed and
validated rigorously: run **all** gates that apply to the change's classified
risk, review the complete diff against the affected invariants, and record a
gate that cannot run as failed instead of skipping it silently. Passing a
subset of the applicable gates does not validate the change.

| Risk | Typical change | Required automated gate | Manual evidence |
| --- | --- | --- | --- |
| R0 | Non-critical docs/meta | contract, link, and path checks | none |
| R1 | Web UI, tests, tooling, pure logic | R0 + focused tests and generated assets | as identified |
| R2 | BLE, network, persistence, OTA, build | full host + ASan/UBSan + TSAN + architecture + every official validation profile pair | subsystem-dependent |
| R3 | Relay, machine, ISR, watchdog, boot, GPIO, partitions, remote control, unknown | R2 + warnings/cppcheck + build variants | HIL/manual required |
| Release | Candidate firmware image | complete analysis, resource budgets, applicable soak, HIL and manual plan | required |

Use `./scripts/dev validate [--risk R0..R3] [paths...]`. Focused commands are
`./scripts/dev test [normal|asan|tsan|web|ble|ota|tooling]`, `./scripts/dev build`, and
`./scripts/dev analyze`. The supported IDF setup and commands remain documented
in [Build](docs/BUILD.md), [scripts](docs/SCRIPTS.md), and
[static analysis](docs/STATIC_ANALYSIS.md). Hardware acceptance is defined by
the [manual test plan](docs/MANUAL_TEST_PLAN.md) and curated evidence by
[target trace qualification](docs/P2_TARGET_TRACE.md).

Any change to `src/OpenBrewByWeightNetwork.cpp`,
`src/network/OpenBrewByWeightHttpLifecycle.inc`, or another source that defines or
registers HTTP routes or handlers must run `./scripts/dev test web`. That profile,
and every R2/R3 validation gate, runs the named `http-route-capacity` check before
the broader Web contracts. The check counts all `registerHandler(server_, ...)`
registrations in the network sources and requires `max_uri_handlers` to be
strictly greater, preserving at least one spare slot.

Missing tools or dependencies fail profiles that require them with exit 127.
Tests never bootstrap packages or access hardware/network implicitly. R3 is not
release-ready while required HIL/manual evidence is pending.
Every versioned firmware budget measurement must build with the `--development`
profile (admin unlock plus the JTAG console), as defined by
`docs/P2_RESOURCE_BUDGETS.md`; normal release builds retain the OTA-slot and
memory-placement checks but have no matching versioned size baseline. A plain
`./scripts/dev build` therefore prints "budget evidence requires a
--development build" and is **not** budget evidence: only the development
profile compares the versioned baselines, so any change that can move image
size (embedded Web assets included) must be verified with a `--development`
build or the R2/R3 gate before it is called done.
R2/R3 validation applies it to all supported built-in profile pairs in
`docs/BUILD_PROFILES.md` and leaves those
measured images in their profile build directories. Image
and memory regions are compared by
`src/tests/check_firmware_size.js` against those versioned budgets.

The documentation check covers root guides, canonical guides in `docs/`, the BLE
library README, and the safety README. Local working files in `temp/`,
`docs/plans/`, and `docs/audits/` are not documentation sources for this check.
They remain part of the local project but outside Git; validate their evidence
and progress through the [AI workflow](docs/AI_WORKFLOW.md#local-project-files-and-git).
The check validates local paths, images, and Markdown heading/
explicit HTML anchors (including duplicate headings and multiline links).
External URLs and example contents are not certified by this offline check.

## Reading a result

A zero exit code means the automated profile passed, not that hardware is
qualified. Use the printed `artifacts/runs/<run-id>/summary.json` and full log
to inspect which steps ran. Exit 127 means a required dependency is missing;
record the gate as failed and prepare the dependency explicitly.

Failed runs keep their evidence: only steps that started can produce
diagnostics, and a failed prerequisite may leave later entries absent in the
run record.

Every environment verifies the required tools are present and runnable
before tests or builds — Node and Cppcheck carry no project version pin, so
the machine's current release is what runs. The Home Assistant checks verify
Python and uv and refuse to update the lockfile during dependency sync;
subsequent integration checks run without syncing. Firmware builds require
ESP-IDF 6.1.0 and reject any change to the IDF component lock during a
build.

Classify concrete files, not a directory name such as `docs`. Safety-related
documents and BLE/OTA references can select R3/R2 even though they are Markdown.
Do not lower risk to avoid an unavailable tool or missing physical evidence.

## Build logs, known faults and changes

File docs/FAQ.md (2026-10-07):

# Troubleshooting

Start with the symptom below. Defaults refer to fresh factory settings; a
saved recipe may differ. [First setup](GETTING_STARTED.md)
covers the normal path.

## Shot and scale

### The shot reached target but did not stop

Check, in order:

1. BBW is on in **Home Quick Settings**, not just in the saved recipe.
2. Home shows fresh usable scale readings.
3. Initial [BBW protection](features/cup-protection.md) has ended.
4. [Fast guard](features/fast-extraction-guard.md) is not deliberately extending.
5. [Original paddle mode](settings/paddle.md#original) is not waiting for OFF.
6. On momentary firmware, the machine state permits an automatic stop pulse.

Use the stop action for your physical switch/mode if the result is unexpected.
[Auto paddle mode](settings/paddle.md#auto) does not interpret OFF as early stop.

### The shot ended above or below target

Read the shot's stop detail on its Stats history card before changing calibration.

| Result | Likely check |
| --- | --- |
| Above target, fast shot | Fast guard may extend toward its recovery weight. |
| Below target, slow shot | Slow guard may choose its recovery floor. |
| Around 50 s on factory Double | Max BBW time; distinct from Slow's 44 s decision. |
| After scale loss | A→M deadline is measured from shot start, not disconnect. |
| Ordinary stop followed by extra dripping | Learned offset and drip delay; see [BBW](features/brew-by-weight.md). |

Prediction, sample timing and dripping mean the weight at stop need not equal
the final stored weight. Guard behavior does not guarantee extraction quality.

### The scale disconnected

Weight stop pauses while reconnection continues. Three coherent readings on
the recovered link can restore it. [A→M](features/auto-to-manual.md) and other
applicable limits still act. A steady unchanged weight is not a lost stream.

If the scale was absent at start, [No-scale BBW](settings/no-scale-bbw.md)
controls whether the attempt is blocked or manual. A scale arriving later
does not retroactively make every manual cycle an automatic one.

### Can I place the cup late or brew without weight control?

A cup placed within the [retare window](features/tare-retare.md) can be tared
automatically. Later placement is not covered. **Require cup to start** blocks
the start instead.

For a timer-only session, turn BBW off in Home. Tare/timer remain available
when supported; weight stop, late retare and Max BBW time do not. Home's
session selection does not overwrite the saved preset.

### Does the 60-second limit always stop water?

It limits electrical relay closure. On paddle installations that normally stops
brewing. A momentary machine needs a stop pulse and valid state conditions;
without scale/reed evidence, a tap-started machine may not receive it. Read
[Momentary limits](settings/momentary.md#stopping-and-time-limits).

## Network and access

### I cannot find the controller's Wi-Fi

On fresh settings, the [AP](settings/ap.md) starts at boot. Its name is
**`OpenBrewByWeightAP-`** plus eight characters unique to this controller.
USB `AP_STATUS` prints the exact name. Forget any saved network named only
`OpenBrewByWeightAP`. With saved Wi-Fi, fallback begins after roughly 25 s
without association. Automatic AP shuts down after 3 minutes with no associated
clients and does not restart after a later successful home-network connection
drops. Use USB `AP_START` or reboot.

### The phone says the Wi-Fi password is wrong

After a factory reset the password is still **`ineedacoffee`**. Phones and
computers often show that message when they cannot finish joining, not only
when the letters are wrong. Join the unique `OpenBrewByWeightAP-xxxxxxxx`
name from USB `AP_STATUS`, forget any unsuffixed `OpenBrewByWeightAP`, and
retry next to the controller. The scale may wait to connect until you finish
this setup network.

### I saved Wi-Fi and the old page never returned

Reconnect your phone/computer to the home network, find the controller's DHCP
address in the router or USB `NET_STATUS`, then open that address and claim
the UI within 3 minutes. The AP address cannot follow a change to a different
network. Unconfirmed changes revert; see [Wi-Fi](settings/wifi.md).

### How do I reach the controller the first time?

Once the controller has joined your home Wi-Fi, open
`openbrewbyweight.local` in a browser on any phone or computer connected to
the same network — there is no need to look up the IP address. The name comes
from the controller's default device name; if you renamed it in
Admin → Network, open `<name>.local` instead (spaces become hyphens, so
`Cafe Bar` is `cafe-bar.local`). See [Wi-Fi](settings/wifi.md#discovery-by-name).

### I cannot open `openbrewbyweight.local`

Usually one of two things is happening. Either the controller never joined
your Wi-Fi (or your phone/computer is on a different network) — check that
both are connected to the same network. Or your network does not allow the
discovery behind `.local` names (mDNS), which guest and hotel networks
commonly block. In that case, find the controller's IP address in your
router's device list and open that instead. See
[Wi-Fi](settings/wifi.md#discovery-by-name).

### Controls are locked or another browser took over

Reload claims the Web UI. Admin unlock is a separate password check. Idle
timeouts, another browser's claim, and an active shot can each restrict
controls for different reasons. See [Web access](GETTING_STARTED.md#web-access).

### I forgot the password or cannot reach any interface

Use [USB commands](SERIAL_CLI.md) or
[physical recovery](EMERGENCY_RECOVERY.md). Resetting only the password over USB
preserves Wi-Fi; access recovery also forgets the network. Factory reset erases
much more. Compare the procedures before choosing one.

### Automatic tare does not happen after switching on

Check **Home → Cup → Automatic tare** and the scale status. With a positive
weight already present at startup, remove the cup, let the empty pan settle,
and replace it. If the Bookoo zeroed a load already on its pan, wait for the
initial zero to settle, remove it, let the negative empty reading settle, then
place a different-weight load. If it returns near zero, readings were lost, or
the negative reading was present from the first connection, tare the empty pan
using the scale's button, reconnect the scale, wait for stable zero and replace the load. Stable-looking
weight alone is insufficient after lost readings or a failed tare; an unchanged
cup is not automatically retried. See
[outside-brew tare](settings/tare.md#outside-a-brew).

### I pressed tare on the scale and the controller did not retare

The controller cannot verify a press of the scale's physical tare button from
the documented weight notifications. A return to 0 g can also mean a previously
removed load was put back. Home may still say **Cup present** and **Tared**
because those are its last known states. Tare the empty pan using the scale's
button, reconnect it, wait for stable zero, then place the cup again. The optional accessory retare
handles one stable addition to a controller-tared cup before a shot; it cannot
identify physical button presses. See [Tare](settings/tare.md#outside-a-brew).

### The scale connects slowly or the UI stutters

Close other scale-connected apps. Check the saved preferred scale and
**Admin → Power management → BLE scan mode**. Factory default is **Balanced**;
Relaxed uses less scanning radio time and Aggressive uses more. Try Relaxed
if idle scanning hurts UI response. On a Linea Micra, the
[machine-aware scale search](settings/linea-micra.md#machine-aware-scale-search)
can ease scanning while the machine is off.
**Admin → Power management → Wi-Fi sleep** can also affect latency.
See [Scales](settings/scales.md) and [Wi-Fi](settings/wifi.md).

### Why is there no remote Start or rinse?

They are disabled in default firmware. An explicit development build can
enable them, but Admin unlock alone cannot. Remote Stop remains privileged.
See [build options](BUILD.md#5-build).

### The web interface only shows the Admin page

The [firmware mode](settings/firmware-mode.md) switch is off: the controller
is running as a transparent pass-through and every other tab is hidden. Unlock
Admin with the device password, open **Firmware**, and turn **Enable Shot
Stopper** back on.

## Hardware and compatibility

### Can I use this firmware with a machine other than Rancilio Silvia Pro X or La Marzocco Linea Micra?

Yes, but first determine and review the correct configuration for that exact
machine and controller assembly. Identify whether its brew control is momentary
or maintained/paddle, whether reliable state feedback such as a reed sensor is
available, how the isolated normally-open relay must connect, and which factory
defaults match the machine's gestures. Then create complete
[hardware and machine profiles](BUILD_PROFILES.md) and pass the applicable
bench and manual tests. A similar connector, brand, or switch appearance is not
proof of electrical or behavioral compatibility.

- **Boards / wiring:** [Hardware](HARDWARE.md). A GPIO map is not a complete
  machine installation guide.
- **Scale models / missing timer or sound:** [compatibility table](../libraries/EspressoScaleBLE/README.md#scale-compatibility).
  Implemented and physically tested support are different.
- **No USB port:** default app CDC needs GPIO4 held to GND at reset.
  ROM download uses BOOT + RST; see [USB console](HARDWARE.md#usb-console-jumper).
- **LED or beeps:** the connection LED is not a brew or safety-ready indicator.
  Output depends on [Alerts](alerts.md), local buzzer and scale capabilities.
- **Change GPIOs:** create or select a reviewed hardware profile and rebuild;
  the Web UI does not configure safety-critical pins.

## Safety and diagnostics

After a watchdog/panic reset, the relay is forced open and the interrupted shot
does not resume. Persistent hardware/feedback faults may still block starting.
An open K1 cannot stop a welded contact; see [isolation](HARDWARE.md#isolation-must).

The **Diagnostic** page is always available at the address `/diagnostic`, even
when its tab is hidden from the menu (Admin → Frontend → **Show diagnostic
page** only shows or hides that tab) and in compatibility mode. Its
measurements keep recording either way. While the page is open, its
**States**, **Machine I/O**, and **Scale** sections — including the scale's
timer — update on their own several times per second, so readings such as the
relay, the switch, the cup, and the weight stay current without reloading;
every other section refreshes every few seconds. The page finishes loading
when those sections have arrived. New log entries appear automatically while
Diagnostic is open, and leaving the page stops its live updates. If the
connection drops, the interface reconnects and reloads current readings.

In **NVS**, unavailable entry and namespace measurements appear as a dash,
so a failed measurement is not mistaken for an empty store.

**Diagnostic → Scale → Profiling** records what the scale actually sent and
what the firmware decided about it. Press **Start** before reproducing a
problem — for example a wrong tare or an unexpected cup event — and **Stop**
when done; **Download** then saves a plain-text trace and **Delete** removes
it. Recording continues until its capacity fills or you press **Stop**, keeps
running while you leave the page, and works with or without a shot in
progress. Every decoded weight is kept exactly as received — including
identical, negative, and rejected readings — together with the tare, cup,
touch, and first-drop decisions taken around it, so a support conversation
can point at one line instead of guessing. Starting a new recording replaces
the previous one, which is stated next to the buttons; a finished recording
survives a restart once it reports as saved. Losing power during recording or
saving can lose that session.

**Capture capacity used** shows how much recording space has been consumed,
including the space kept for the closing event. **Elapsed** is the time already
recorded. **Estimated time remaining** adapts to how quickly readings and events
arrive, so different scales can record for different lengths of time. It takes
a few seconds to appear, smooths brief changes in activity, and may increase
when fewer events arrive. If no records arrive for several seconds, the estimate
returns to **Estimating…**; recording stays active.
The percentage describes the capture, while **Saving…** and **Saved** tell you
whether it has been stored for a restart. Stopping early keeps the actual
percentage used rather than changing it to 100%.
The state also explains recording errors, such as insufficient memory or a
failed save. If saving fails and **Download** remains available, download the
trace before restarting to preserve the recording held in memory.

On a 16 MB controller, **Diagnostic → Misc → Coredump** shows how many complete
crash records are saved, up to two. Unlock Admin to download them. The browser
saves a `.tar.gz` file when gzip is supported, or a `.tar` file otherwise.
Extract it with `tar -xzf <archive.tar.gz>` or `tar -xf <archive.tar>`.
Each crash folder contains the raw core dump, a short address list, and a
manifest with the matching firmware ELF fingerprint. Use the ELF from that
exact build when interpreting addresses. A watchdog dump may contain several
tasks; the short address list describes only the panic callback's view.
The archive can contain passwords or other private data, so share it only with
someone you trust. Downloading does not delete records. **Empty** asks for
confirmation and permanently removes them; a full factory reset does too.
An incomplete panic or a reboot loop before the record is copied can leave
fewer than two records. The screen reports an error if a temporary dump cannot
be archived. The 8 MB profile does not offer persistent crash downloads.

To report an issue, include firmware version, board and machine type, scale
model/firmware, exact gesture/settings, and redacted diagnostic export. Never
include passwords or webhook secrets. [USB HEALTH](SERIAL_CLI.md#diagnostics)
and [shot history](features/shot-history.md) help explain the observed result.

A `stale scale event rejected` warning means an old weight update or scale
command was ignored. Its detail names the rejected item and reason; `gen(e/n)`
and `disc(e/n)` compare the event's link identifiers (`e`) with the current
link (`n`).
This can happen briefly after a scale disconnects or reconnects.

## Where to change it

Use the [settings index](README.md#settings) for parameter references,
[OTA troubleshooting](features/ota.md#session-start-troubleshooting) for update
errors, and [webhook troubleshooting](features/webhooks.md#troubleshooting)
for delivery problems.

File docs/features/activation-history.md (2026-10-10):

# Activation history

The activation history is a simple, independent diary of machine activations
and paddle attempts: shots, rinses, short runs, recognized machine wake
gestures, and attempts stopped by No-scale BBW protection. It shows what
happened and what you tried, without the measurement detail of the
[shot history](shot-history.md).

## What is recorded

Every activation the machine confirmed is recorded when its circuit opens,
including manual brews and rinses that the shot history skips. A paddle attempt
stopped by No-scale BBW protection is recorded when you release the paddle.
Each entry keeps the UTC instant and local time calculated with the zone's
offset when the activation ends, as well as its duration and type:

- **Shot** — an activation that outlasted the brew-by-weight protection
  window (12 seconds by default). The label records the intention to brew,
  even when no measured shot is saved in [Stats](shot-history.md).
- **Rinse** — a quick rinse cycle.
- **Backflush** — an automatic cleaning activation confirmed through the
  [Micra integration](../settings/linea-micra.md#automatic-backflush), shown with
  a cleaning-drop icon. Duration measures how long its activation circuit was
  closed. An interrupted confirmed backflush keeps this label; it does not
  certify that detergent cleaning finished, and it never counts in Stats.
- **Other** — a confirmed activation that ended within the protection
  window or exactly at its end, such as a brief paddle blip.
  A backflush attempt that opened the circuit before confirmation also records
  Other, regardless of duration. Waiting requests and refused starts add no row.
- **Power ON** — a paddle gesture recognized as a Linea Micra standby wake.
  It records how long the paddle kept the wake circuit active but never counts
  as a shot in Stats.
- **No scale guard aborted** — a paddle attempt that No-scale BBW protection
  prevented from starting. It records how long the attempt lasted, including
  repeated attempts in Require a scale mode, and never counts as a shot.

Other abandoned starts, where the machine never confirmed the activation,
record nothing. When the controller's clock has never synced, cards show
"no time" until it gets the time from the network.

A recognized Linea Micra standby wake creates one **Power ON** entry when the
paddle returns to OFF. See
[Linea Micra](../settings/linea-micra.md#recognize-paddle-wake-gestures).

The log holds up to **1000** activations. When it fills, the oldest entry is
dropped to make room for the newest. Entries enter memory when a cycle ends.
Flash saving follows when the controller is idle, so recording never slows down
a brew.

## In the Web UI

Open the **History** page (next to Stats) to browse the diary. The entries and
the sort and Clear controls normally appear at once with their data; a brief
loading animation covers them only while the device has not sent the initial
data yet — for example right after the interface starts or after a dropped
connection. From then on the diary keeps refreshing in the background while
you are on other pages, so History always opens instantly. The list loads
**20 entries at a time** as you scroll. New or deleted entries refresh the list
automatically from the first page; scroll to load more again. Sort by date,
newest or oldest first, from the sort control at the top. Each card leads with
the duration large on the left and the friendly time label small on the right:
"Today" or "Yesterday" with the clock time to the minute, the weekday name for
the rest of the week, "2 weeks ago" for older weeks, and a short date like
"Sep 15" for older entries. Hovering the label shows the exact date and time.
The activation type sits below as a small label. Shots carry a coffee-cup
icon on the left of the card. Rinses carry a droplet, and other
activations carry a lightning bolt, Power ON entries use the power symbol,
and No scale guard aborted entries show an X. When the clock
was not synced when the entry was recorded, the card shows "no time"
instead of a date.

Narrow the diary to what you care about with the Filter control next to the
sort order. It opens a checklist of activation types — Shot, Rinse, Backflush,
Power ON, Other, and No scale guard aborted — and you can tick as many as you
like. With nothing ticked the diary shows everything; ticking one or more
types shows only those, and the list updates as you tick. While a filter is
active the Filter button shows a count badge and stays highlighted, so the
state is visible at a glance, and Reset at the top of the checklist clears it
in one tap. The checklist closes when you tap outside it or press Escape, and
it works the same on a phone and on a computer. If the entries you are
filtering for are older than what has loaded, the list keeps loading more
pages on its own until it finds them or reaches the end; when a filter
matches nothing at all, the page says so instead of showing an empty diary.

Changing the saved time zone later does not rewrite earlier entry times.

Take the diary into a spreadsheet with the Export button. It downloads an
`activation-history.csv` file with every entry — its date and time, the UTC
timestamp, the duration, and the type — in the current sort order, newest or
oldest first, exactly as the page is set.

Delete a single entry with the ✕ on its card, or clear the whole diary with
the Clear button. Clearing asks for an explicit confirmation and cannot be
undone.

## Stats vs History

The two pages record different things and never substitute for each other:

| | Stats (shot history) | History (activation diary) |
| --- | --- | --- |
| Records | Brews with a valid settled yield over 2 g | Confirmed activations and paddle attempts blocked by No-scale BBW protection |
| Minimum duration | Longer than 12 seconds | Longer than the configured BBW protection window to carry a Shot label |
| Detail | Goal, yield, error, flow, guards, rating, curve | Time, duration, type |
| Capacity | 100 shots | 1000 activations |

A measured shot appears in both. A longer activation without a valid yield
can appear as Shot here while staying out of Stats. Deleting or clearing in
one page never touches the other.

USB: see [USB serial CLI](../SERIAL_CLI.md) for factory reset, which clears
both logs.

Related: [Shot history](shot-history.md), [Brew by weight](brew-by-weight.md),
[Wi-Fi](../settings/wifi.md) (timezone for time labels).

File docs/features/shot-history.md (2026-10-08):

# Shot history

Completed shots with a measured yield are stored on the controller and shown
in the Web UI shot log. Use it to see how long a shot ran, why it ended, and
how close it landed to the target when brew by weight was in use.

When you open **Stats**, the Stats section, including its chart, and the
Shot history section, including its sort, export, and clear controls, normally
appear at once with their data. A brief loading animation covers them only
while the device has not sent the shot data yet — for example right after the
interface starts or after a dropped connection. From then on the data keeps
refreshing in the background even while you are elsewhere in the interface, so
the page always opens instantly with the latest shots.

Stopwatch and gram-weight icons sit beside the large duration and yield values
in each shot card and beside Avg time and Avg yield in the Stats summary.
Each icon and value are centered together within their column. The icons
follow your chosen light or dark theme. History cards use equal left and right
spacing for their measurements and charts, with the delete button in the top
right corner.

## What is recorded

A confirmed, non-rinse cycle becomes a shot when it lasts **more than 12 seconds**
and its settled final yield is valid and **more than 2 g**. Manual stops,
timer-only brews, normal BBW cuts, guard stops, and time or safety limits all
use this same rule. A cycle without a valid measured yield cannot qualify.
The 12-second recording rule is fixed; changing BBW's start-of-shot protection
time changes weight stopping, not which completed cycles are recorded.

Typical fields include local time (from the saved time zone at shot end),
duration, the exact preset name captured at shot start, goal and yield (the
shot's actual output), error, average flow, first-drop time, the scale used
(your chosen name, otherwise the suggested model name, or the advertised
Bluetooth name when neither is available), the late-tare time when the cup was
tared mid-shot, whether Fast/Slow
guards ran or extended the shot, `shot_type`, `cut_type`
(`auto`, `manual`, `limit`), `stop_detail` (for example
`normal_target`, `activator`, `web_stop`, `wall_limit`, `hard_limit`,
`extended_max_weight`, `cup_removed`), and a manual `rating` from 0
(unrated) to 5. Rate a stored shot from its history card; tapping the current
star again clears the score. A friendly end time, such as “Today at 19:06”,
appears on the Stats history cards; it is shown only when the clock was set
when the shot finished. The preset snapshot is shown on the Home shot hero
card and on every Stats history card. Renaming or deleting a preset later does
not rewrite a shot's displayed name.

**Scale** appears after **Preset** and keeps the name captured for that shot,
even if the scale disconnects or is renamed later. **Rate** aligns with the
middle column; long scale names wrap within the first column. Existing shots
keep their original names. A Bluetooth name longer
than the friendly-name limit is shortened to fit. **Tare time**, before
**1st drop**, shows the successful late tare's elapsed shot time, or **None**
when no late tare succeeded. Its chart label always uses one decimal, such
as **3.0 s**. The initial shot-start tare is not a late tare.

If a late retare succeeds and a fresh reading confirms its new zero, an earlier
first-drop time and marker are discarded. Later coffee can supply a new time
and marker; without that replacement, first-drop time and **Avg flow** are
unavailable. The rest of the shot curve is retained. **Tare time** records
successful command completion, so it can also appear when zero was not
confirmed and the earlier first-drop record was kept.

The log holds up to **100** shots. The following are never stored:

- Rinses and starts that were not confirmed
- Cycles lasting 12 seconds or less
- Cycles whose final yield is missing, invalid, or 2 g or less

Home shows the current activation as it happens. After the machine stops, its
duration stays fixed while accepted drip readings continue updating the curve.
The shot card shows yield and target, such as **36.2 g / 36 g**. Its capsules
appear in this order: elapsed time (**36.8 s**), **first drop**, **Avg flow**,
**Err**, and the cutoff reason. First drop includes its time, such as
**first drop 6.2 s**. Err shows the percentage above or below the target,
such as **Err 0.6%**; unavailable measurements are hidden.
The timer comes from the controller and pauses on screen if the connection is
lost; **Reconnecting…** indicates that the displayed result may be stale.

If an activation does not qualify for Stats, the page that observed it keeps
its result for 30 seconds after analysis finishes, then returns to the latest
recorded shot. A temporary reconnection preserves the remaining interval;
reloading the page opens the latest recorded shot instead. Starting another
activation immediately replaces the temporary result. Confirmed activations
also appear in the separate [activation history](activation-history.md).
BBW offset learning and A→M samples keep their own eligibility rules.

The controller collects accepted scale readings in memory while the shot runs
and saves the completed curve after the configured drip delay. Each reading
keeps its actual arrival time, including repeated weights and changing scale
cadence. Duration ends when the machine circuit opens. During the drip delay,
accepted readings continue as a faint dashed line without fill. A small hollow
circle marks the last reading when it matches the settled **Yield**.
The drip readings keep their actual times and never change the earlier curve
or its flow. Older shots without recorded drip readings keep their original
curve; no drip tail is reconstructed from the final weight alone.
Isolated readings and event weights appear as small dots at the curve's line
thickness, including when the chart is stretched across a wide screen.

A curve can hold 1201 readings within 60 seconds of shot start, including
the drip tail. If the readings exceed either limit, the captured prefix
remains available and the chart says **Incomplete curve**. Brew stopping and
the shot's summary still work. Known rejected readings, a new tare reference
and scale loss leave breaks in the curve. A healthy slow scale does not
create a break merely because its readings are farther apart. An incomplete
tail has no final-yield circle. Removing or replacing the cup ends drip capture.

The first-drop marker and late-tare cup marker keep their event times. Fast,
Slow and A-to-M colors identify changes without adding competing time labels;
the time axis uses 10-second references. Home shows the live memory curve
during a shot and the newest eligible history row's exact curve while idle.

Observed removal or a new placement during the drip delay preserves the weight
captured at shot end and discards post-drip learning, regardless of the idle
automatic-tare setting. A single fresh reading consistent with the known empty
pan is enough to discard this optional analysis, but cannot trigger a replacement
tare. If a physical swap is completely absent from the scale notifications,
weight alone cannot establish that the final reading belongs to another cup.

## In the Web UI

Open the shot history table to browse rows, delete one entry, clear the
whole log, or export CSV. Clearing requires an explicit confirm.

Home and Stats read the same shot history. Deleting the newest shot shows the
next newest qualifying shot on Home; clearing the log empties the idle card.
Factory reset clears both histories. The [activation history](activation-history.md)
records every confirmed activation, including rinses and cycles that do not
qualify as shots. Deleting or clearing shot history never changes that diary.
New rows appear after the configured drip delay. If flash saving is still
pending, the API reports `savePending`; a failed write remains pending for retry.
Once saving completes, the newest shot and its curve survive a restart.
Power loss before saving completes can still lose pending changes.

When you first open **Stats**, both **Stats** and **Shot history** show a loading
wave. They fade away together once the summaries and history are ready. The
wave over Stats does not add space to the panel or resize it when it disappears.
With Wi-Fi sleep enabled, a large history may take a little longer to appear.
You can leave the page while it loads and return later.

Sort the list by **Date** or **Rating**, ascending or descending. Date
defaults to newest first. Rating puts unrated shots (0 stars) at the end
in both directions; equal scores keep newer shots first. The table loads
**10 shots at a time** as you scroll. Changes arrive automatically while the
page is open. After an entry is added, rated, or deleted, the list refreshes
from the first page in your chosen order; scroll to load more again. Export CSV
downloads the full log newest-first, independent of the on-screen sort. A large
export can take up to 90 seconds on a slow connection. Wait for the download
before changing the sort or leaving Stats.

The Time column reads the way people talk: "Today" or "Yesterday" with the
clock time to the minute, the weekday name for the rest of the week, then
"2 weeks ago" for older weeks, and a short date like "Sep 15" (with the year
when it is not the current one). Hovering a time shows its exact date and
time to the second, and the CSV export always keeps that full detail no
matter how the table displays it.

Stats uses up to the newest **10 qualifying shots** for duration, yield, available
flow, daily count, and the duration chart, regardless of how the table is
sorted. **Avg BBW error** independently uses up to the newest **10 normal BBW
target cuts** in the full history, skipping manual shots and Fast/Slow guard
stops. It averages the absolute percentage miss, so overshoots and undershoots
cannot cancel each other. It is unavailable when there is no qualifying BBW
target cut. For example, a single 28.0 s Fast-guard shot yielding 36.9 g with
1.42 g/s average flow shows those same three averages; **Avg BBW error** stays
unavailable until a normal BBW target cut is recorded. **Daily shots**
averages the dated shots over the calendar days they span, including both ends.
An erase-all firmware installation starts with empty shot history.
If a low-weight older row is imported later, it remains in the table and CSV
but does not enter Home or these summaries.

Every available weight curve has a **Flow rate (g/s)** chart directly below it
on Home and in its Stats history card. Both charts share a time axis, including
any recorded drip tail, with reference lines every 10 seconds. The Weight chart adds lines every 10 g, and
Flow rate adds them every 0.5 g/s. Each displayed range rounds up to the next
reference interval and each chart grows vertically when all required labels
would not fit at its normal compact height.
On a narrow screen, a few numbers beside these charts may be hidden when they
would overlap. The lines and measurements stay in place, and more numbers
appear again when there is room. Home applies the same rule to the time and
weight references above the shot on its hero card, which always pairs the
measured weight with the target, shown as `35.4 / 36 g` where the shot
actually landed, while the target alone still marks its own position; when the
two labels are too close, the paired measured/target label is the one that
stays visible. The hero keeps showing the exact measured weight.

The Flow rate chart measures the weight change over the preceding second using
the readings' actual arrival times. If a second starts between two readings,
their weights supply an interpolated starting value. The whole window needs
continuous readings on or after first drop. Before enough readings arrive,
or after a known rejection, tare or scale-loss break, measured flow is unavailable.
The flat line before first drop is only a visual reference. With uninterrupted
readings, a short visual connection joins it to the first available flow point.
That connection is not a measured rate and does not contribute to Max flow or
the CSV export. Known interruptions remain gaps.

Each estimate is drawn at the middle of its measurement window, usually half a
second before the latest reading. With a healthy scale reporting less often
than once per second, flow describes the actual longer span between readings
and is drawn at its midpoint. A long interval alone cannot distinguish a slow
scale from an interruption that the controller could not detect. Repeated weights
are retained. When several readings share an arrival time, the last one supplies
the endpoint; earlier readings at that time have no separate flow value.
Event annotations and settled yield never enter the measured flow series.
Flow calculations preserve first-drop and cutoff timing to the millisecond,
so readings just before the cutoff remain available and a window cannot start
before first drop.

The cards call shot output **Yield** while chart, goal, scale, and cup labels
continue to use Weight where they describe weight itself. **Avg flow** remains
the final yield divided by the time after first drop. **Max flow** is the highest
non-negative estimate from supported windows ending before or at machine cutoff; Home
shows the peak so far during a live shot, and saved cards reproduce it from
the stored observations. Falling weight contributes 0 g/s. Max flow is
unavailable when the curve has no supported window. For an **Incomplete curve**,
Max flow is marked **(recorded)** and describes only the captured portion of the
shot. Recorded post-stop readings also support flow estimates using the same
calculation. Their chart continuation is faint, dashed and unfilled from the
machine's cutoff time onward. Drip flow does not change **Max flow** or shot
duration. Each estimate stays at its window midpoint, so the flow line can end
before the last weight reading; it is not extended with an assumed zero.
No extra smoothing changes the plotted values.

The controller stores only the weight curve. The Flow rate chart and Max flow
are derived locally, so viewing or reloading them does not create another
history record or flash write.

## Read a result

The CSV exports `local_time` as the local date and time saved for that shot,
`ended_at_unix` as UTC Unix seconds, and `tz_off` as the signed offset in
minutes applied when it ended. For example, two shots in `America/Santiago`
may have different `tz_off` values in winter and summer. Changing the saved
zone later does not recalculate either row. If the clock was unavailable,
`has_wall_time` is `0` and all three time cells are empty. A zone name is not
recorded per shot.

CSV retains the scalar shot columns, including `yield_g`,
`yield_source`, `max_flow_g_s`, the BBW fields and `preset_id`.
After those columns, `curve_truncated` reports `1` for an incomplete
capture and `0` otherwise. `curve_break_before` lists the zero-based
indices of readings starting a new segment, separated by semicolons.

Each reading has an ordinal group: `sample_1_time_s`,
`sample_1_weight_g`, `sample_1_flow_g_s`, then the same three columns
for sample 2 and so on. Times are the original elapsed arrival times in
seconds, weights are grams, and flow is grams per second. A flow cell stays
empty when that reading has no supported flow window. Recorded drip readings
include their supported flow estimates too. The time is the window's
ending observation time, while the chart uses its midpoint; arrival times retain
millisecond precision (up to three decimal places in seconds). The chart,
Max flow and CSV use the same estimates. Missing curves
and groups beyond a shot's captured length leave empty cells. The export
does not resample to a grid, so different scale cadences remain visible without
creating a column for every distinct arrival time.

The underlying curve JSON pairs centigram weights in `wCg` with integer
elapsed milliseconds in `wAtMs`. `wBreakBefore` supplies the same
segment-start indices and `wTruncated` reports completeness.
Spreadsheets using the former `yield_dt_s`, `yield_<time>s` or
`flow_<time>s` columns must switch to these ordinal sample groups.

`preset_id` (JSON `presetId`) and JSON `presetName` are captured from the preset
used for that shot, not the currently selected recipe. The name is a snapshot,
not a lookup through the mutable preset list, so it survives switching, renaming,
or deleting the preset. Pre-V3 records have unknown identity (JSON 0, CSV empty),
IDs are
local to the controller, use 1–255 and may be reused after allocation wraps or
settings are reset; use the captured name when comparing historical shots.

`offset_g` is the compensation captured at shot start, **before learning**,
in grams at 0.01 g storage resolution. Zero is valid. It is not the baseline,
next learned offset or measured post-shutdown water. `bbw_alpha` is also
captured at shot start: **Linear regression + offset correction** (`legacy`, v1)
uses 1.00; historical adaptive EWMA v1 may use 0.10, 0.30, 0.50 or 1.00.
EWMA v2 supports exact hundredths from 0.01 through 1.00, including custom
gains such as 0.37. It is not a gain selected after this shot's result.
Learning applied is `1`/`0` in CSV and true/false in JSON; a skipped shot still
retains its assigned gain. For example, appended CSV values can be
`linear_ewma,2,0.37,1` and later `linear_ewma,2,0.50,1` for the same preset.

The one-time USB curve-layout update starts the old weight curves empty while
preserving settings, shot summaries and activation history. Subsequent firmware
updates can use OTA. See [Build](../BUILD.md#curve-layout-transition).
The algorithm column is descriptive: it records the policy each shot ran
under, including `legacy` for shots recorded before that mode was removed.
It has been a read-only identity for a while and is not a setting.

Algorithm identity describes the shot's configured policy even when a guard
or manual action ends it; use `stop`, `shot_type` and `cut_type` to interpret
the outcome. EWMA time/safety-limit outcomes remain in eligible history with
learning-applied false; only a normal weight-target cut can train EWMA.
Compare shots like for like using each shot's captured `bbw_alpha`,
`offset_g` and the firmware identity recorded alongside the dataset; recipe
changes and resets belong in those notes too. Export the CSV before a firmware
update so pre-update shots keep their original algorithm identity.

Average flow uses final weight (including accepted post-drip) minus baseline,
divided by duration after first drop. It is not terminal flow at cutoff.
The Flow rate chart is different: it shows the non-negative weight change over
supported measurement windows and can rise or fall throughout the shot.
Error and average flow share final weight algebraically, so their correlation
does not prove a residual-flow mechanism. The dashed weight tail shows captured
post-stop drips; the flow chart also shows their supported rates as a dashed
continuation. See
[BBW learning](brew-by-weight.md#cutoff-behavior-and-learning).

| Stop detail | Meaning |
| --- | --- |
| `normal_target` | Normal weight endpoint, including offset/prediction |
| `touch_weight_fallback` | Touch protection blocked the weight stop and the sustained-weight backup ended the shot; Ended shows Touch fallback on Home and Stats, matching Home Assistant's Last shot stop detail |
| `extended_max_weight` / `extended_min_time` | Fast guard extended the shot |
| `slow_max_time` / `slow_min_weight` | Slow guard reached its recovery boundary |
| `auto_to_manual` | Scale-loss time guard |
| `activator` / `web_stop` | Physical / authenticated Web stop |
| `wall_limit` / `hard_limit` | Operational / hard time limit |
| `cup_removed` | Cup-removal protection requested stop |

For example, 39 g against a 36 g goal with a Fast stop detail is not the same
calibration problem as a normal target cut followed by excess drip. Check the
reason before resetting learned offset. A live 2 s cycle can appear on Home,
but once completed it is excluded from shot history and does not replace the
idle last-shot card. An unrated shot uses rating 0.

USB: `CLEAR_SHOTS` (see [USB serial CLI](../SERIAL_CLI.md)).

Related: [Brew by weight](brew-by-weight.md), [FAQ](../FAQ.md),
[Wi-Fi](../settings/wifi.md) (timezone for wall-clock labels).

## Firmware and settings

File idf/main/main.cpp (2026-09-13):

#include "Arduino.h"
#include "esp_attr.h"

// Small BSS probe. With ALLOW_BSS enabled this must land in PSRAM
// (typically 0x3c0xxxxx). On Arduino-ESP32 the same attribute is a no-op
// and the linker would put it in internal DRAM (0x3fcxxxxx). Sized just
// large enough for ./scripts/dev build to verify placement — not 8 KiB.
extern "C" {
EXT_RAM_BSS_ATTR uint8_t g_probe[256];

// Arduino releases BLE controller memory from initArduino() unless a linked
// Arduino BLE library marks it as used. Shot Stopper uses ESP-IDF NimBLE
// directly, so no Arduino library installs that marker. Keep BLE memory alive
// before setup() starts; releasing it is irreversible and makes the later
// nimble_port_init() controller startup access freed storage.
bool bleInUse(void) { return true; }
}

// Keep g_probe in the ELF so ./scripts/dev build can still prove ALLOW_BSS.
extern "C" void shotstopperKeepBssProbe(void) {
  g_probe[0] = static_cast<uint8_t>(g_probe[0] + 1U);
}

// Application setup()/loop() live in the shotStopper component
// (src/shotStopper.cpp), started by CONFIG_AUTOSTART_ARDUINO.

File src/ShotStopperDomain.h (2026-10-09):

#pragma once
#include <atomic>
#include <cmath>
#include <new>
#include <type_traits>
#include <stddef.h>
#include <stdint.h>
#include <stdio.h>
#include <string.h>
#include "ShotStopperBuildProfile.h"
#include "ShotStopperSafety.h"
#include "ShotStopperHwmon.h"
#include "ShotStopperBbwTypes.h"

// Map ESP-IDF Kconfig (main/Kconfig.projbuild) onto the historical
// SHOT_STOPPER_* macros. Command-line -DSHOT_STOPPER_*=… wins (ifndef).
#ifndef SHOT_STOPPER_ENABLE_REMOTE_MACHINE_CONTROL
#ifdef SHOT_STOPPER_ENABLE_REMOTE_CN9
#define SHOT_STOPPER_ENABLE_REMOTE_MACHINE_CONTROL SHOT_STOPPER_ENABLE_REMOTE_CN9
#endif
#endif
#if !defined(SHOT_STOPPER_HOST_TEST) && __has_include("sdkconfig.h")
#include "sdkconfig.h"
#ifndef SHOT_STOPPER_ENABLE_REMOTE_MACHINE_CONTROL
#ifdef CONFIG_SHOT_STOPPER_ENABLE_REMOTE_MACHINE_CONTROL
#define SHOT_STOPPER_ENABLE_REMOTE_MACHINE_CONTROL 1
#elif defined(CONFIG_SHOT_STOPPER_ENABLE_REMOTE_CN9)
#define SHOT_STOPPER_ENABLE_REMOTE_MACHINE_CONTROL 1
#else
#define SHOT_STOPPER_ENABLE_REMOTE_MACHINE_CONTROL 0
#endif
#endif
#ifndef SHOT_STOPPER_ENABLE_BUZZER
#ifdef CONFIG_SHOT_STOPPER_ENABLE_BUZZER
#define SHOT_STOPPER_ENABLE_BUZZER CONFIG_SHOT_STOPPER_ENABLE_BUZZER
#endif
#endif
#ifndef SHOT_STOPPER_MACHINE_TYPE
#ifdef CONFIG_SHOT_STOPPER_MACHINE_TYPE
#define SHOT_STOPPER_MACHINE_TYPE CONFIG_SHOT_STOPPER_MACHINE_TYPE
#endif
#endif
#ifndef SHOT_STOPPER_DEVELOPMENT
#ifdef CONFIG_SHOT_STOPPER_DEVELOPMENT
#define SHOT_STOPPER_DEVELOPMENT 1
#else
#define SHOT_STOPPER_DEVELOPMENT 0
#endif
#endif
#ifndef SHOT_STOPPER_ENABLE_JTAG
#ifdef CONFIG_SHOT_STOPPER_ENABLE_JTAG
#define SHOT_STOPPER_ENABLE_JTAG CONFIG_SHOT_STOPPER_ENABLE_JTAG
#endif
#endif
#endif

#include "ShotStopperMachineTypes.h"
#include "ShotStopperMachinePaddleConfig.h"
#include "ShotStopperScaleTypes.h"
#include "ShotStopperBrewTypes.h"
#include "ShotStopperNetworkTypes.h"
#include "ShotStopperTimeZone.h"

namespace shotstopper {

constexpr uint32_t SERIAL_BAUD = 115200;
// Settings v3 preserves the v1/v2 layout; authenticated records upgrade on read.
// Other historical layouts still require the documented USB erase workflow.
constexpr uint32_t CONFIG_SCHEMA_VERSION = 3;

constexpr size_t NTP_SERVER_HOST_CAPACITY = 64;
constexpr uint32_t NTP_RESYNC_INTERVAL_MS = 3600UL * 1000UL;
constexpr uint32_t NTP_UNSYNCED_RETRY_MS = 15UL * 1000UL;
constexpr uint32_t NTP_FIRST_SYNC_TIMEOUT_MS = 10UL * 1000UL;
// Post-GOT_IP settle before SNTP may arm. IP is already assigned (WL_CONNECTED
// only fires on ARDUINO_EVENT_WIFI_STA_GOT_IP), so this only covers brief
// DHCP/gateway warm-up; failures self-heal via retry plus server failover.
constexpr uint32_t NTP_STA_SETTLE_MS = 1000;
constexpr uint32_t NTP_STALE_AFTER_MS = 24UL * 3600UL * 1000UL;
constexpr uint8_t NTP_MAX_CONSECUTIVE_FAILURES = 255;

enum class NtpServerPreset : uint8_t {
  POOL = 0,
  GOOGLE = 1,
  CLOUDFLARE = 2,
  NIST = 3
};

// Single source for NTP preset renderings (API id and hostname), indexed by
// NtpServerPreset; invalid presets fall back to POOL like the old switches.
inline constexpr struct {
  const char *hostname;
  const char *apiId;
} kNtpPresetLabels[] = {
    {"pool.ntp.org", "pool"},
    {"time.google.com", "google"},
    {"time.cloudflare.com", "cloudflare"},
    {"time.nist.gov", "nist"},
};

constexpr size_t kNtpPresetLabelCount =
    sizeof(kNtpPresetLabels) / sizeof(kNtpPresetLabels[0]);

static_assert(kNtpPresetLabelCount == 4,
              "keep kNtpPresetLabels in sync with NtpServerPreset");

inline size_t ntpPresetLabelIndex(uint8_t preset) {
  return preset < kNtpPresetLabelCount ? preset : 0U;
}

inline const char *ntpPresetHostname(uint8_t preset) {
  return kNtpPresetLabels[ntpPresetLabelIndex(preset)].hostname;
}

inline const char *ntpPresetId(uint8_t preset) {
  return kNtpPresetLabels[ntpPresetLabelIndex(preset)].apiId;
}

enum class NoScaleBbwMode : uint8_t {
  OFF = 0,
  WARN_ONCE = 1,
  REQUIRE_SCALE = 2
};

// Independent option bits share this persisted byte; low bits stay 0–2.
constexpr uint8_t NO_SCALE_ALLOW_RINSE_WHILE_ARMED = 0x80U;
constexpr uint8_t IDLE_ACCESSORY_RETARE = 0x40U;

inline uint8_t noScaleBbwModeValue(uint8_t stored) {
  return static_cast<uint8_t>(stored & 0x03U);
}

inline bool noScaleAllowRinseWhileArmed(uint8_t stored) {
  return (stored & NO_SCALE_ALLOW_RINSE_WHILE_ARMED) != 0;
}

inline bool idleAccessoryRetareEnabled(uint8_t stored) {
  return (stored & IDLE_ACCESSORY_RETARE) != 0;
}

inline uint8_t packNoScaleBbwMode(uint8_t mode, bool allowRinseWhileArmed) {
  return static_cast<uint8_t>(
      (mode & 0x03U) | (allowRinseWhileArmed ? NO_SCALE_ALLOW_RINSE_WHILE_ARMED : 0U));
}

inline bool validNoScaleBbwMode(uint8_t stored) {
  return (stored & ~0xC3U) == 0 &&
         noScaleBbwModeValue(stored) <=
             static_cast<uint8_t>(NoScaleBbwMode::REQUIRE_SCALE);
}

inline bool noScaleBbwEnabled(uint8_t stored) {
  return noScaleBbwModeValue(stored) != static_cast<uint8_t>(NoScaleBbwMode::OFF);
}
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

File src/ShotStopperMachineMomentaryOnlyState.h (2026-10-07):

#pragma once

// =============================================================================
// SPECIALIZATION: Momentary-only — run view (state)
// =============================================================================
// WHAT: MachineRunState without reed. Never canonical: boot is OFF, a missing
//       scale is UNKNOWN (no auto-cut), quiet pan reinforces OFF, and
//       espresso-like rising flow (g/s) is the only path to CONFIRMED_ON.
//       Flow uses BLE sample spacing, not the control-loop period: a still-
//       fresh reading resampled every few ms must not reset the rising window,
//       or the state stays ASSUMED_ON and auto-cut never pulses. A tare-like
//       drop to ~0 g rebases the shot baseline even before CONFIRMED_ON, so
//       start tare / late-cup retare are visible to inference. CONFIRMED_ON
//       expires without recent flow so auto-cut cannot pulse a stopped group.
//       A logical stop goes to ASSUMED_OFF (stop-settling) until the pan is
//       quiet, including after the stop-ack timeout. Cup REMOVED while
//       ASSUMED_OFF settles to CONFIRMED_OFF immediately (MachineSense edge).
//       A Start that never confirms espresso and stays within 1 g of the shot
//       baseline until HARD_MAX_CIRCUIT_CLOSED_MS settles to CONFIRMED_OFF
//       (no pulse) so the stopper can abandon the cycle. Espresso-like confirm
//       vetoes that idle for the rest of the logical run, even after Confirmed
//       on expires. Consumes MachineSense pushed by the stopper.
//
// BOUNDARY: This file alone determines momentary-only run state. Do not put
// reed GPIO here (that is MomentaryReedState). Do not put paddle latch logic
// here. Brew/guards must not re-derive this — they use machineRunState().

constexpr float MOMENTARY_FLOW_ON_G_S = 0.60f;
constexpr float MOMENTARY_FLOW_OFF_G_S = 0.20f;
constexpr float MOMENTARY_TARE_RESET_G = 1.0f;
constexpr float MOMENTARY_FINGER_JUMP_G = 15.0f;
constexpr float MOMENTARY_FLOW_CONFIRM_MAX_G_S = MOMENTARY_FINGER_JUMP_G;
constexpr float MOMENTARY_BASELINE_BAND_G = 0.5f;
constexpr float MOMENTARY_NO_FLOW_IDLE_BAND_G = 1.0f;
constexpr float MOMENTARY_CONFIRM_DELTA_G = 1.0f;
constexpr uint32_t MOMENTARY_FLOW_HOLD_MS = 500;
constexpr uint32_t MOMENTARY_FLOW_GAP_SKIP_MS = 500;
constexpr uint32_t MOMENTARY_QUIET_MS = 1000;
constexpr uint32_t MOMENTARY_STOP_ACK_MS = 1500;
constexpr uint32_t MOMENTARY_STOP_RETRY_AFTER_MS = 600;
constexpr uint32_t MOMENTARY_CONFIRM_MIN_RUN_MS = 800;
constexpr uint32_t MOMENTARY_STALE_UNKNOWN_MS = 1500;

MachineRunState momentaryInferredState = MachineRunState::CONFIRMED_OFF;
bool momentarySawScale = false;
bool momentaryEspressoConfirmed = false;
bool momentaryHadEspressoConfirm = false;
bool momentarySawEspresso = false;
float momentaryShotBaselineG = 0.0f;
float momentaryQuietBaselineG = 0.0f;
uint32_t momentaryQuietSinceMs = 0;
float momentaryLastWeightG = 0.0f;
uint32_t momentaryLastWeightAtMs = 0;
uint32_t momentaryLastWeightSequence = 0;
uint32_t momentaryRisingSinceMs = 0;
uint32_t momentaryLowFlowSinceMs = 0;
bool momentaryStopAwaitingAck = false;
uint32_t momentaryStopAwaitingSinceMs = 0;
bool momentaryStopRetryPending = false;
bool momentaryStartAwaitingAck = false;
uint32_t momentaryStartBaselineSinceMs = 0;
bool momentaryOrphanRun = false;
uint32_t momentaryStaleSinceMs = 0;
bool momentaryFirmwareCutPending = false;
bool momentarySettledWeightCutArmed = false;
bool momentaryStopSettling = false;
bool momentaryNoFlowIdlePending = false;

bool reedIsOn() { return false; }

inline float momentaryLiveWeightG() { return machineSense.weightG; }

void noteMomentaryEspressoConfirmed() {
  momentaryEspressoConfirmed = true;
  momentaryHadEspressoConfirm = true;
  momentarySawEspresso = true;
}

void noteMomentaryLogicalStart() {
  momentaryInferredState = MachineRunState::ASSUMED_ON;
  momentaryEspressoConfirmed = false;
  momentaryHadEspressoConfirm = false;
  momentarySawEspresso = false;
  momentaryRisingSinceMs = 0;
  momentaryLowFlowSinceMs = 0;
  momentaryStopAwaitingAck = false;
  momentaryStopRetryPending = false;
  momentaryQuietSinceMs = 0;
  momentaryStartAwaitingAck = true;
  momentaryStartBaselineSinceMs = 0;
  momentaryOrphanRun = false;
  momentaryStaleSinceMs = 0;
  momentaryFirmwareCutPending = false;
  momentarySettledWeightCutArmed = false;
  momentaryStopSettling = false;
  momentaryNoFlowIdlePending = false;
  if (machineSense.weightFresh) {
    momentarySawScale = true;
    const float weight = momentaryLiveWeightG();
    momentaryShotBaselineG = weight;
    momentaryQuietBaselineG = weight;
    momentaryLastWeightG = weight;
    momentaryLastWeightAtMs = millis();
    momentaryLastWeightSequence = machineSense.weightSequence;
  } else {
    momentaryShotBaselineG = 0.0f;
  }
}

void noteMomentaryLogicalStop() {
  if (!momentaryLogicalRunActive &&
      momentaryInferredState == MachineRunState::CONFIRMED_OFF &&
      !momentaryStartAwaitingAck) {
    return;
  }
  momentaryEspressoConfirmed = false;
  momentaryRisingSinceMs = 0;
  momentaryLowFlowSinceMs = 0;
  momentaryStopRetryPending = false;
  momentaryStartAwaitingAck = false;
  momentaryStartBaselineSinceMs = 0;
  momentaryStopSettling = true;
  if (!machineSense.weightFresh) {
    momentaryStopAwaitingAck = false;
    if (momentarySettledWeightCutArmed) {
      momentaryInferredState = MachineRunState::ASSUMED_OFF;
      return;
    }
    momentaryStopSettling = false;
    momentaryInferredState = momentarySawScale ? MachineRunState::UNKNOWN
                                       : MachineRunState::CONFIRMED_OFF;
    return;
  }
  momentaryStopAwaitingAck = true;
  momentaryStopAwaitingSinceMs = millis();
  momentaryInferredState = MachineRunState::ASSUMED_OFF;
}

void noteMomentaryLogicalStartCanceled() {
  momentaryEspressoConfirmed = false;
  momentaryHadEspressoConfirm = false;
  momentaryRisingSinceMs = 0;
  momentaryLowFlowSinceMs = 0;
  momentaryStopAwaitingAck = false;
  momentaryStopRetryPending = false;
  momentaryStartAwaitingAck = false;
  momentaryStartBaselineSinceMs = 0;
  momentaryOrphanRun = false;
  momentaryStopSettling = false;
  momentaryNoFlowIdlePending = false;
  momentaryInferredState = MachineRunState::CONFIRMED_OFF;
}

void noteMomentaryDisqualifiedPress(bool restoreRunning) {
  if (!restoreRunning) {
    noteMomentaryLogicalStartCanceled();
    return;
  }
  momentaryStopAwaitingAck = false;
  momentaryStopRetryPending = false;
  momentaryStartAwaitingAck = false;
  momentaryStartBaselineSinceMs = 0;
  momentaryOrphanRun = false;
  momentaryStopSettling = false;
  momentaryInferredState = momentaryGesturePreState;
  if (momentaryInferredState == MachineRunState::CONFIRMED_OFF) {
    momentaryInferredState = MachineRunState::ASSUMED_ON;
  }
}
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

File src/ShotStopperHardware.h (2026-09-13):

#pragma once

#include <stdint.h>

#include "ShotStopperDomain.h"

namespace shotstopper {

// Board hardware — ESP32-S3 only. Named profiles resolve assembled variants;
// legacy --arch builds retain the historical defaults below.
#if !defined(SHOT_STOPPER_HOST_TEST)
#if !defined(ARDUINO_ESP32S3_DEV)
#error "Unsupported board: Shot Stopper requires ESP32-S3 (esp32:esp32:esp32s3)"
#endif
#if !defined(BOARD_HAS_PSRAM)
#error "Shot Stopper requires PSRAM. Compile n8r4 (QSPI 4MB) or n16r8 (OPI 8MB)"
#endif
#endif

#if defined(ARDUINO_ESP32S3_DEV)
#ifndef SHOT_STOPPER_ACTIVATOR_GPIO
#define SHOT_STOPPER_ACTIVATOR_GPIO 21
#endif
#ifndef SHOT_STOPPER_RELAY_GPIO
#define SHOT_STOPPER_RELAY_GPIO 2
#endif
#ifndef SHOT_STOPPER_SCALE_CONNECTED_LED_GPIO
#define SHOT_STOPPER_SCALE_CONNECTED_LED_GPIO 1
#endif
#ifndef SHOT_STOPPER_BUZZER_GPIO
#define SHOT_STOPPER_BUZZER_GPIO 14
#endif
#ifndef SHOT_STOPPER_USB_CONSOLE_GPIO
#define SHOT_STOPPER_USB_CONSOLE_GPIO 4
#endif
#ifndef SHOT_STOPPER_ACTIVATOR_ACTIVE_LEVEL
#define SHOT_STOPPER_ACTIVATOR_ACTIVE_LEVEL LOW
#endif
#ifndef SHOT_STOPPER_RELAY_CLOSED_LEVEL
#define SHOT_STOPPER_RELAY_CLOSED_LEVEL HIGH
#endif
#ifndef SHOT_STOPPER_RELAY_OPEN_LEVEL
#define SHOT_STOPPER_RELAY_OPEN_LEVEL LOW
#endif
#ifndef SHOT_STOPPER_ACTIVATOR_DEBOUNCE_MS
#define SHOT_STOPPER_ACTIVATOR_DEBOUNCE_MS 30
#endif
#ifndef SHOT_STOPPER_SCALE_STATUS_LED_PRESENT
#define SHOT_STOPPER_SCALE_STATUS_LED_PRESENT 1
#endif
#ifndef SHOT_STOPPER_SPEAKER_PRESENT
#define SHOT_STOPPER_SPEAKER_PRESENT 1
#endif
#ifndef SHOT_STOPPER_USB_CONSOLE_JUMPER_PRESENT
#define SHOT_STOPPER_USB_CONSOLE_JUMPER_PRESENT 1
#endif
#ifndef SHOT_STOPPER_SCALE_CONNECTED_LED_ACTIVE_LEVEL
#define SHOT_STOPPER_SCALE_CONNECTED_LED_ACTIVE_LEVEL HIGH
#endif
#ifndef SHOT_STOPPER_USB_CONSOLE_ACTIVE_LEVEL
#define SHOT_STOPPER_USB_CONSOLE_ACTIVE_LEVEL LOW
#endif
#ifndef SHOT_STOPPER_REED_PRESENT
#if SHOT_STOPPER_MACHINE_TYPE == 2
#define SHOT_STOPPER_REED_PRESENT 1
#else
#define SHOT_STOPPER_REED_PRESENT 0
#endif
#endif
#else
#error "Unsupported board: Shot Stopper requires ESP32-S3"
#endif

constexpr uint8_t ACTIVATOR_GPIO = SHOT_STOPPER_ACTIVATOR_GPIO;
constexpr uint8_t RELAY_GPIO = SHOT_STOPPER_RELAY_GPIO;
constexpr bool SCALE_STATUS_LED_PRESENT =
    SHOT_STOPPER_SCALE_STATUS_LED_PRESENT == 1;
constexpr bool SPEAKER_PRESENT = SHOT_STOPPER_SPEAKER_PRESENT == 1;
constexpr bool USB_CONSOLE_JUMPER_PRESENT =
    SHOT_STOPPER_USB_CONSOLE_JUMPER_PRESENT == 1;
constexpr bool REED_PRESENT = SHOT_STOPPER_REED_PRESENT == 1;
constexpr uint8_t SCALE_CONNECTED_LED_GPIO =
    SHOT_STOPPER_SCALE_CONNECTED_LED_GPIO;
constexpr uint8_t SCALE_CONNECTED_LED_ACTIVE_LEVEL =
    SHOT_STOPPER_SCALE_CONNECTED_LED_ACTIVE_LEVEL;
constexpr uint8_t SCALE_CONNECTED_LED_INACTIVE_LEVEL =
    SCALE_CONNECTED_LED_ACTIVE_LEVEL == HIGH ? LOW : HIGH;
// Fast blink while GATT connecting (5 Hz); slow blink while weight is stale (1 Hz).
constexpr uint32_t SCALE_LED_FAST_BLINK_MS = 100;
constexpr uint32_t SCALE_LED_SLOW_BLINK_MS = 500;
constexpr uint8_t BUZZER_GPIO = SHOT_STOPPER_BUZZER_GPIO;
constexpr uint8_t USB_CONSOLE_GPIO = SHOT_STOPPER_USB_CONSOLE_GPIO;
// Dupont IO4 to a GND pad (never the EN column). Sampled once at boot.
constexpr uint8_t USB_CONSOLE_ACTIVE_LEVEL =
    SHOT_STOPPER_USB_CONSOLE_ACTIVE_LEVEL;

constexpr uint8_t ACTIVATOR_ACTIVE_LEVEL =
    SHOT_STOPPER_ACTIVATOR_ACTIVE_LEVEL;
// Active-HIGH relay: GPIO HIGH energizes the coil and closes NO.
constexpr uint8_t RELAY_CLOSED_LEVEL = SHOT_STOPPER_RELAY_CLOSED_LEVEL;
constexpr uint8_t RELAY_OPEN_LEVEL = SHOT_STOPPER_RELAY_OPEN_LEVEL;

#if SHOT_STOPPER_MACHINE_TYPE == 2
#ifndef SHOT_STOPPER_REED_GPIO
#define SHOT_STOPPER_REED_GPIO 13
#endif
#ifndef SHOT_STOPPER_REED_ACTIVE_LEVEL
#define SHOT_STOPPER_REED_ACTIVE_LEVEL LOW
#endif
#ifndef SHOT_STOPPER_REED_DEBOUNCE_MS
#define SHOT_STOPPER_REED_DEBOUNCE_MS 30
#endif
constexpr uint8_t REED_GPIO = SHOT_STOPPER_REED_GPIO;
constexpr uint8_t REED_ACTIVE_LEVEL = SHOT_STOPPER_REED_ACTIVE_LEVEL;
constexpr uint32_t REED_DEBOUNCE_MS = SHOT_STOPPER_REED_DEBOUNCE_MS;
#endif

constexpr uint32_t ACTIVATOR_DEBOUNCE_MS =
    SHOT_STOPPER_ACTIVATOR_DEBOUNCE_MS;
#ifndef SHOT_STOPPER_SAFETY_HEARTBEAT_TOGGLE_MS
#define SHOT_STOPPER_SAFETY_HEARTBEAT_TOGGLE_MS 50
#endif
#ifndef SHOT_STOPPER_CIRCUIT_FEEDBACK_SETTLE_MS
#define SHOT_STOPPER_CIRCUIT_FEEDBACK_SETTLE_MS 100
#endif
constexpr uint32_t SAFETY_HEARTBEAT_TOGGLE_MS =
    SHOT_STOPPER_SAFETY_HEARTBEAT_TOGGLE_MS;
constexpr uint32_t CIRCUIT_FEEDBACK_SETTLE_MS =
    SHOT_STOPPER_CIRCUIT_FEEDBACK_SETTLE_MS;

#if defined(SHOT_STOPPER_SAFETY_HEARTBEAT_GPIO) != \
    defined(SHOT_STOPPER_CIRCUIT_FEEDBACK_GPIO)
#error "Define both safety heartbeat and circuit feedback GPIOs, or neither"
#endif
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

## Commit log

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2026-09-06 fix F-05. Orphaned persistence queue on task creation failure and F-06. BOOT_READY flag set before mandatory mechanisms are available
    [ShotStopperDomain.h, ShotStopperMachineRelay.h, shotStopper.cpp]
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2026-09-07 Expand NVS partition and harden storage recovery
    Increase NVS capacity, enforce safe USB layout migration, expose storage diagnostics, and recover factory reset only from confirmed NVS exhaustion.
    [partitions-n16r8.csv, partitions-n8r4.csv]
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2026-09-07 Distinguish diagnostic history rotation from unread log loss
    Removed the recurring diagnostic log overrun warning.
    Kept the 96-entry bounded ring and legacy dropped API field.
    Added historyOverwritten, missedEvents, serialDropped, hasMore, and cursorInvalid.
    Calculated events and metadata atomically under the existing mutex.
    Added an independent Web UI log cursor per boot.
    Displayed rotation, actual missed events, and serial loss separately.
    Added tests for rotation, pagination, stale cursors, exact loss counting, and absence of overrun warnings.
    [ShotStopperDomain.h, shotStopper.cpp]
2026-09-07 Fix scale BLE write races and disconnect diagnostics
    - Isolated ATT completion from worker wakeups.
    - Preserved recoverable links and original GAP disconnect causes.
    - Prevented duplicate start/tare commands after uncertain failures.
    - Fixed consecutive-invalid-packet counting.
    - Added separate disconnect and command-failure diagnostics, plus 86 production-adapter regression checks.
    Validation passed: host 19/19, ASAN/UBSAN 19/19, TSAN 7/7, web contracts, architecture, n8r4/n16r8 builds, Cppcheck and compiler warnings. [R3 results](/Users/felipe/Repos/AcaiaArduinoBLE/artifacts/runs/20260907T220737Z-68675/summary.json).
    [ShotStopperDomain.h]
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2026-09-08 Add automatic tare on cup placement outside brews
    Changes made:
    - Reused the existing cup FSM, stability detection and tare executor.
    - Idle tare triggers only on confirmed ABSENT → PRESENT; shot completion never triggers it.
    - Known tared cups at 0 g satisfy the cup-start guard.
    - Added request cancellation and ordering protection against stale tares entering a new shot.
    - Updated settings labels, persistence migration, documentation and regression tests.
    [ShotStopperCupPresence.h, ShotStopperDomain.h]
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2026-09-08 feat: add preset-aware adaptive BBW cutoff and shot history
    Add selectable Legacy and linear/EWMA cutoff strategies with per-preset
    offsets, adaptive learning, editable reset baselines and settings migration.
    Record the cutoff method, profile, alpha, learning result and preset in shot
    history and CSV exports while preserving fixed persisted record sizes.
    Reject forced-cutoff EWMA training, route delayed learning and UI resets to
    the original preset, and validate compact history lengths before reading.
    Remove redundant persistence scratch initialization, reducing the reported
    n16r8 development image by 3680 bytes without raising resource budgets.
    Update canonical behavior, storage and manua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
    [ShotStopperDomain.h, shotStopper.cpp]
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2026-09-09 feat(network): add configurable Wi-Fi discovery
    Advertise the STA HTTP service through Espressif mDNS and expose Device name
    in Admin Network settings. Validate and persist the DNS label independently
    of Wi-Fi credentials, confirm the asynchronous write, and reset it on a
    factory reset without changing the existing settings schema.
    Keep mDNS lifecycle calls in the network manager, roll back failed startup,
    bound retries to five seconds, and stop discovery for shot/scale-connect
    gates and HTTP, AP, or network teardown. Reject startup after RF transitions.
    Add persistence, actual-source lifecycle and UI completion tests. Update
    resource accounting, ownership and user guides, and define hardw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
    [ShotStopperDomain.h]
2026-09-09 feat(power): add state-based power management
    Add an opt-in, persistent Admin setting for idle energy savings while
    preserving fixed 80 MHz operation when disabled. Migrate older settings
    with power management off and keep the setting outside shot presets.
    - Allow 40-80 MHz idle, hold 80 MHz for waiting/manual/rinse activity,
    and request 160 MHz for weighted shots, including scale loss.
    - Track independent WebUI presence and five-minute physical-use cooldowns.
    - Apply owner-local BLE and Wi-Fi policies and use XTAL for the independent
    safety timer without enabling light sleep.
    - Bound BLE wake recovery, preserve worker-health reporting, and route
    unrecoverable controller failures thro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
    [ShotStopperDomain.h, shotStopper.cpp]
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2026-09-09 fix(power): enable power management by default
    - Enable power management for fresh, factory-reset, and migrated settings.
    - Preserve existing Wi-Fi sleep defaults and persisted V11 choices.
    - Update persistence coverage and the power-management setting guide.
    [ShotStopperDomain.h]
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2026-09-10 fix(network): decouple Wi-Fi sleep from power management
    - select WIFI_PS_MAX_MODEM whenever the saved Wi-Fi sleep preference allows it
    - preserve WIFI_PS_NONE for AP, OTA, disconnected STA, and disabled sleep
    - prevent power management, WebUI activity, and scale state from changing Wi-Fi sleep
    - update network contracts and canonical Wi-Fi and power-management documentation
    [ShotStopperDomain.h]
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2026-09-12 fix(first-flow): align drop evidence and curve boundaries
    - use one detector authority for first-drop timestamp and weight
    - propagate the first qualifying sample through session, curve, retare, and webhook consumers
    - reject curve vertices before an exact first-drop event and retain the latest endpoint evidence
    - add firmware and Web regressions and document the observable timing behavior
    [ShotStopperBrew.h, shotStopper.cpp]
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2026-09-12 feat(history): add one-second weight and flow curves
    - persist 61 one-second weight samples in a dedicated dual-slot shotcurve partition
    - derive matched Home and Stats flow-rate charts without a duplicate persistent series
    - enforce clean USB migration for incompatible partition tables and document resource bounds
    - extend firmware, Web, persistence, and partition contracts for the V2 layout
    [partitions-n16r8.csv, partitions-n8r4.csv]
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2026-09-12 feat(home-assistant): add native controller integration
    - add the unauthenticated trusted-LAN integration API with bounded webhook and durable preset contracts
    - publish a Home Assistant 2026.9 custom integration with push reconciliation, transactional webhook setup, preset selection, diagnostics, and extracted project branding
    - migrate webhook and last-shot persistence for preset events and missed-shot recovery while preserving firmware safety gates
    - replace the legacy YAML workflow with canonical user and protocol documentation, CI validation, fixtures, and regression coverage
    - address independent firmware and Home Assistant review findings with verified rollback, ordering, migration, a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
    [ShotStopperDomain.h, shotStopper.cpp]
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2026-09-12 feat(home-assistant): restore shots and expose quick controls
    - persist and restore complete last-shot and last-good-shot aggregates at startup
    - add capability-gated REST and webhook contracts for all Home Quick Settings
    - create non-optimistic Home Assistant switches driven by confirmed push updates
    - add a restart button backed by the existing shot-safe queued restart path
    - mark runtime failures unavailable and recover through bounded backoff or boot push
    - remove periodic coordinator polling and retain bounded reconciliation triggers
    - cover coherent refresh, persistence rollback, startup ordering, entity, and safety behavior
    [ShotStopperDomain.h, shotStopper.cpp]
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2026-09-13 fix(history): unify last-good shot publication
    - make LastShotStore the authoritative idle Home and Home Assistant aggregate
    - resolve ratings and curves through exact history links under one store mutex
    - preserve qualifying-shot semantics across reboot, deletion, and persistence failures
    - prevent the startup webhook retry from recursively acquiring the store lock
    - add host, persistence, Web contract, and TSAN regression coverage
    - align architecture, integration, ownership, and user-facing history documentation
    [ShotStopperDomain.h, shotStopper.cpp]
2026-09-13 fix(resources): harden ESP32-S3 resource ownership
    - reuse the boot persistence buffer, unwind failed BLE startup safely, bound NimBLE drains, replace the task-only buzzer spinlock, and make network progress atomic
    - gate and defer reset-history writes, serialize live mirrors, back off real persistence failures, restore shot curves after failed compaction, correct NVS accounting, and retain watchdog margin
    - require live READY and complete machine-idle gates for OTA confirmation, and enforce the qualified n8r4/n16r8 sdkconfig without retuning clocks or partitions
    - release avoidable Web UI flash and browser memory without changing routes, copy, controls, visible layout, or polling cadence
    -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
    [ShotStopperBuzzer.h, ShotStopperDomain.h, shotStopper.cpp]
2026-09-13 fix(resources): close remediation concurrency gaps
    - publish the BLE worker handle atomically and serialize wake-versus-delete lifetime
    - skip reset-history flash locking until a checkpoint is actually due
    - refresh the buzzer synchronization rationale and add regression contracts
    - preserve BLE cadence, persistence cadence, and existing safety behavior
    [ShotStopperBuzzer.h]
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2026-09-13 feat(build): add hardware and machine build profiles
    - define X1 hardware variants with optional reed capability and open metadata
    - add explicit Silvia Pro X and Linea Micra machine configurations
    - validate profile compatibility, safe overrides, GPIO ownership, and relay polarity
    - embed resolved hardware and machine identities in diagnostics and OTA
    - document profile schemas, defaults, capability matching, and extension workflow
    [ShotStopperBuildProfile.h, ShotStopperDomain.h, ShotStopperHardware.h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]
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2026-09-13 feat(dev)!: unify firmware workflows under the dev facade
    - add ordered build, flash, OTA, and monitor pipelines to scripts/dev
    - preserve profile validation, saved defaults, USB discovery, and stage-specific options
    - separate OTA automatic approval from post-boot confirmation
    - prevent device credentials from being passed through process arguments
    - move focused ESP-IDF stages under scripts/internal and remove legacy public wrappers
    - expand offline pipeline coverage and document the unified interface comprehensively
    BREAKING CHANGE: legacy *-idf scripts and --force are no longer supported; use scripts/dev pipelines with --yes and --wait-for-confirmation.
    [main.cpp]
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2026-09-16 feat(control): refuse Armed rinse unless Allow rinse while Armed
    Stop a Warn-once Armed rinse from starting water by default. The
    gesture still uses up the missing-scale warning so the next brew can
    be manual; an opt-in setting restores the previous rinse-while-Armed
    behavior.
    Control:
    - Refuse beginRinseCycle while Armed unless the new flag is on.
    - Consume the warning, keep K1 open, and do not fall back to native 1:1.
    - Apply the same policy to paddle, momentary/reed, and Home Start rinse.
    - Re-arm on mode change only, not when toggling the rinse flag.
    Persistence and API:
    - Bump settings schema to V13 without growing RuntimeConfig.
    - Pack Allow rinse while Armed as bit 7 of noScaleBbwMo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
    [ShotStopperDomain.h]
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2026-09-17 feat(history): add independent activation history with PSRAM-backed flash stores
    Add an activation-history diary that records every confirmed machine
    activation (shot, rinse, or short run) beside the stats shot log, and move
    both logs onto dedicated dual-slot flash partitions through a new
    ActivationStores data layer that is the single owner of the three ring
    stores. Every store access (control-loop append, HTTP page queries and
    mutations, deferred flush, factory reset, boot loads) runs under the
    existing shotStoreMutex; only the flash-writing methods additionally take
    the shared flash I/O lock, and appends stay O(1) PSRAM writes with
    persistNow=false so the control loop never waits on flash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
    [partitions-n16r8.csv, partitions-n8r4.csv]
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2026-09-17 fix(persistence): defer BLE scan and WiFi STA confirm/revert flash writes
    Root cause: two paths bypassed the deferred persistence layer and wrote
    NVS synchronously from time-sensitive tasks. The BLE_SCAN_INTENSITY web
    command performed an un-gated dual-slot NVS write on the 1 ms Arduino
    control loop (reachable mid-shot or mid-scale-connect, with the flash
    cache disabled stalling control and PSRAM), and the WiFi STA
    confirm/revert flows persisted the full settings blob on the network
    task without the shared durable-write gate.
    - Stage BLE scan intensity on the control loop (bleScanPersistMux-guarded
    pending/intensity state) and flush it from the settings_persist worker
    under durableFlash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
    [ShotStopperDomain.h, shotStopper.cpp]
2026-09-17 perf(control,network): share loop link snapshot and rate-limit idle status polling
    - Fetch one ScaleLinkSnapshot per control-loop iteration and thread it
    through the per-iteration consumers (drive permission, loop guards,
    machine sense, runtime persistence, weight-stream telemetry, scale LED,
    weight freshness helpers) instead of re-copying it 7-11 times per
    millisecond under the link spinlock; the two contract-fixed event drains
    keep their own fresh fetches.
    - Hoist serviceWeightStreamTelemetry out of serviceControlStatusPublish to
    the loop so it reuses the shared snapshot; publishControlStatus now
    passes its own snapshot to it and to currentWeightIsFresh.
    - Inline the single-c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
    [shotStopper.cpp]
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2026-09-17 feat(admin,ble): make the quiet-scan backoff an Admin setting
    Expose the idle discovery backoff introduced in d5e33aa as the Admin →
    Bluetooth "Idle scan backoff" select, so operators can choose how long the
    hunt keeps full strength and can disable it.
    - Add BleScanCommandPayload (flag bits plus intensity/backoff) to the scale
    types and replace the flat WebCommand scan fields with it, keeping
    ShotStopperDomain.h at its 3300-line architecture ceiling.
    - Bump the dual-slot BLEC store to V3: reuse one reserved byte as
    scanBackoffMin so the blob size is unchanged, keep accepting V2 blobs and
    normalize them to the 5-minute default, and require that default in
    factory verification. P8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
    [ShotStopperDomain.h, shotStopper.cpp]
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2026-09-18 fix(scale,control): close BLE scan audit findings on ownership and results
    - Move the scan-boost no-scale gate and scaleLinkAvailable() into the scale
    worker so the Arduino loop only forwards the machine ON edge, keeping the
    whole boost rule (gate, deadline, duty override) in ScaleService.
    - Replace the single pending ble-scan request id with a four-deep FIFO ring
    so every superseded PUT reports PERSISTED after the combined dual-slot
    save instead of dropping all but the newest id; drain under the staging
    mutex and report outside it (host case BC08).
    - Accept the legacy "light"/"normal" scan-intensity wire ids as parse
    aliases (never emitted) and correct the stale INVALID_BLE_CONF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
    [shotStopper.cpp]
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2026-09-19 feat(micra): add BLE integration foundation
    - select Linea Micra support from the validated build profile and exclude concrete sources from non-Micra images
    - add the bounded native NimBLE protocol client, shared radio arbiter, and worker-owned read-only service foundation
    - add V15 credential, binding, option, and per-preset temperature persistence with V1-V14 migration coverage
    - preserve scale priority, critical cancellation, relay behavior, and zero additional task ownership
    - extend host, BLE, profile, persistence, and preset contract tests and update the measured NVS resource budget
    [ShotStopperBuildProfile.h, ShotStopperDomain.h, ShotStopperMicraService.h]
2026-09-19 refactor(machine): isolate machine-specific integrations
    - reduce the shared machine boundary to lifecycle, configuration, and worker hooks
    - move Linea Micra settings, requests, status, and policy into its owning module
    - select concrete adapters and dependencies explicitly from validated build profiles
    - add variant-aware architecture and translation-unit isolation checks
    - fix the V14-to-V15 persistence migration scratch overflow
    - document machine integration ownership, BLE arbitration, and extension rules
    [ShotStopperDomain.h, ShotStopperLineaMicraTypes.h, ShotStopperMicraService.h]
2026-09-19 fix(micra): harden BLE ownership and request lifecycle
    - serialize Micra callback, configuration, request, candidate, and status state
    - cancel and terminate preempted GAP procedures without losing teardown events
    - bound JSON nesting before allocation and replace the arbiter spin lock
    - reject unfinished target reconciliation and isolate optional Micra boot failures
    - add concrete service, cancellation, sanitizer, and architecture regressions
    Fix races, leaked BLE procedures, false request confirmation, avoidable heap pressure, and cross-machine startup coupling found during the Micra audit.
    [ShotStopperMicraService.h]
2026-09-19 feat(micra): add Web setup and read-only state monitoring
    - expose profile-gated Micra token, pairing, preset-temperature, and diagnostic controls
    - persist credentials and verified bindings without returning the token
    - observe machine mode with bounded shared-BLE scans, retries, cooldowns, and stale-state handling
    - isolate Micra capabilities from common machine lifecycle and paddle control
    - document setup, API behavior, scheduling, reset, and manual qualification
    This completes the Web and read-only state slice while preserving scale priority, relay safety, and existing behavior for other machine profiles.
    [ShotStopperDomain.h, ShotStopperLineaMicraTypes.h, ShotStopperMicraService.h]
2026-09-19 fix(micra): harden read-only state monitoring
    Correct pairing retry timing, unsupported-state expiry, cross-task binding publication, BLE candidate validation, token lifetime, stack usage, and Web runtime size.
    Fix retry starvation, stale diagnostics, credential retention, unsafe cross-task reads, and fragile candidate persistence in the Linea Micra read-only integration.
    [ShotStopperLineaMicraTypes.h, ShotStopperMicraService.h]
2026-09-19 fix(micra): repair BLE discovery and connection writes
    Accumulate connectable advertisements and scan-response names by peer, select only verified MICRA candidates, use MTU-aware GATT writes, reset negotiated MTU between sessions, and gate duplicate Web actions while requests are active.
    Fix Micra discovery failures caused by requiring the local name and connectability in the same BLE packet, and avoid unnecessary long writes that diverged from the working Home Assistant client.
    [ShotStopperMicraService.h]
2026-09-19 fix(micra): add bounded BLE connection diagnostics
    - log scan admission, discovery counts, eligible candidates, connection stages, raw failures, retries, and arbiter health through the existing logger
    - keep advertisement processing allocation-free and prevent credentials, response payloads, arbitrary names, and BLE addresses from reaching logs
    - cover successful association, denied scans, malformed advertisements, terminal connection errors, and log redaction
    Fix Micra failures exposing only communication_error without enough evidence to identify the failing BLE stage.
    [ShotStopperMicraService.h]
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2026-09-19 fix(micra): skip incompatible anonymous BLE peers
    - Fix repeated pairing attempts against anonymous devices that do not expose the Micra GATT contract.
    - Retain a bounded heap-free rejection cache across retries and connection tests.
    - Log complete candidate addresses, preserve the fixed RAM envelope, and add regression coverage and pairing documentation.
    [ShotStopperMicraService.h]
2026-09-19 fix(micra): target the configured BLE machine
    Fix crowded BLE environments selecting unrelated peripherals instead of the configured Linea Micra.
    - add an exact Micra BLE address setting to the Web UI and API
    - stop probing anonymous nearby peripherals by signal strength
    - accept only the configured address or one uniquely named MICRA device
    - verify the selected peer before promoting it to a persistent binding
    - preserve scale priority and read-only machine behavior
    - add discovery, persistence, Web UI, and ambiguity regression coverage
    [ShotStopperMicraService.h]
2026-09-20 feat(micra): replace BLE transport with cloud API
    - remove the Linea Micra BLE client and restore scale-only BLE ownership
    - add signed STA-only cloud authentication, machine discovery, selection, and read-only state polling
    - add V16 credential migration, secure disconnect cleanup, Web UI workflow, tests, and documentation
    - preserve shot-time polling suspension and validate all supported build profiles
    This replaces unreliable BLE discovery while isolating Micra changes from other machine profiles.
    [ShotStopperBuildProfile.h, ShotStopperDomain.h, ShotStopperLineaMicraTypes.h]
2026-09-20 fix(micra): harden cloud state lifecycle
    - preserve the BLE and scale implementation at the requested baseline
    - reset cloud sessions between accounts and clear stale machine observations
    - report unknown state for eco mode, failures, and expired samples
    - resume cloud observations immediately after shot or network gating
    - remove obsolete Micra BLE documentation and diagnostic references
    - raise measured firmware image and total-size margins
    This fixes cross-account session reuse, stale state reporting, orphaned BLE references, and Micra firmware size validation failures.
    [ShotStopperDomain.h, ShotStopperLineaMicraTypes.h]
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2026-09-20 fix(micra): streamline cloud polling and diagnostics
    Fix redundant authentication and TLS setup caused by renewing tokens immediately before state reads and closing the reusable HTTP session.
    - Renew cached access tokens at 50 minutes in a separate polling cycle.\n- Reuse the cloud HTTP connection across state requests.\n- Align the account email field with the shared input styling.\n- Replace the diagnostic refresh button with an accessible inline link.\n- Extend contracts and documentation for the corrected behavior.
    [ShotStopperMicraService.h]
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2026-09-20 fix(micra): release idle cloud memory
    - allocate Micra session and I/O PSRAM lazily and release them at lifecycle boundaries
    - route Micra TLS records through dynamic size-aware allocation while preserving other machine profiles
    - add build and contract guards and refresh measured resource documentation and baselines
    This fixes boot-lifetime PSRAM fragmentation and retained internal TLS buffers introduced by cloud state polling.
    [ShotStopperMicraService.h]
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
